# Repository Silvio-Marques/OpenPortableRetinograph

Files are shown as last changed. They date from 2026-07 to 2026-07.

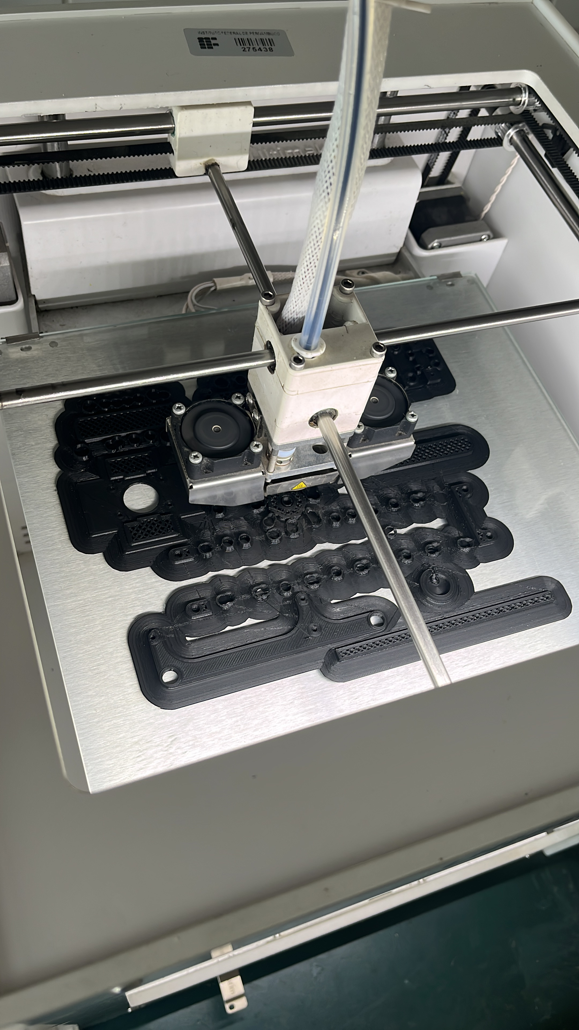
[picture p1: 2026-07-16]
images/Development/8934499A-B4BF-47F2-9E4D-7AB6EEFE7587.JPG

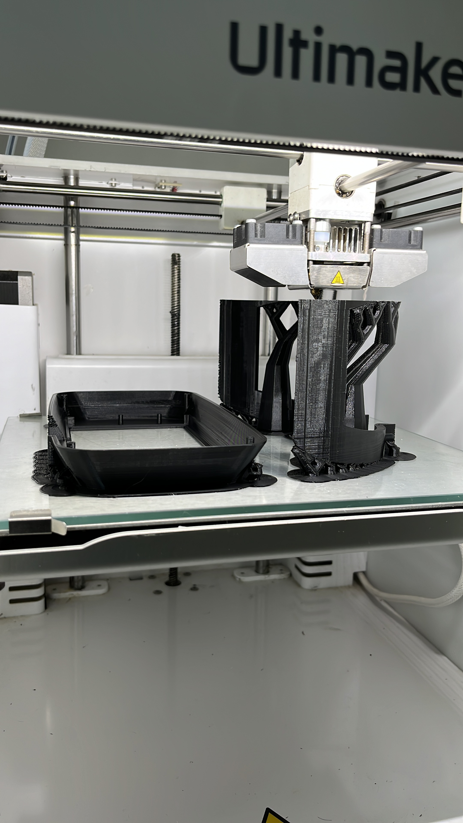
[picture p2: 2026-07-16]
images/Development/956187B9-EA5F-4862-9C40-ECFD5C4E084D.JPG

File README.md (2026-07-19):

# Open Portable Retinograph (OPR)

**Development of an Open-Source Portable Raspberry Pi-Based Retinograph for Retinal Image Acquisition and Automated Retinopathy Screening**

---

# Authors

**Developed by**

Silvio Marques (IFPE)

**Advisors**

Tiago Lima (IFPE)

Helio Bentzen (IFPE)

David Ribeiro (IFPE)

**Institution**

IFPE – Palmares Campus

Maker Laboratory – Palmares Campus

Brazil

---

# About the Project

The **Open Portable Retinograph (OPR)** is an open-hardware project developed to provide a portable, low-cost platform for retinal fundus image acquisition.

The project combines additive manufacturing, commercially available optical components, and a Raspberry Pi-based embedded platform to enable retinal image acquisition using open-source hardware, with a focus on research, education, and future automated retinopathy screening applications.

The system architecture was designed to reduce the cost of conventional retinal imaging devices, facilitate replication by other institutions, and provide a platform for the future integration of embedded Artificial Intelligence algorithms.

---

# License

This project is distributed under the **MIT License**.

The CAD files, technical documentation, source code, and computational models may be used, modified, and redistributed under the terms of the license.

---

# Disclaimer

This equipment is intended exclusively for research, technological development, and educational purposes.

The prototype **is not certified for clinical use** and must not be used for medical diagnosis without the appropriate approval from the relevant regulatory authorities.

---

# Software Ecosystem

The retinograph was designed with a modular architecture, allowing integration with different Artificial Intelligence systems for the analysis of acquired retinal images.

## OpenDR

Automated Diabetic Retinopathy screening system.

**Repository:**

https://github.com/heliobentzen/openDR

**Key Features**

* Automated image acquisition
* Web interface
* TensorFlow Lite
* Grad-CAM
* Report generation
* Automatic classification

---

## Glaucoma AI

Deep Learning–based system for glaucoma classification from retinal images.

**Demo:**

https://huggingface.co/spaces/tiagopessoalim/glaucoma

**Intended Applications**

* Diagnostic second opinion
* Glaucoma screening support

---

# Version

**Current Version**

**v1.0.0 (Functional Prototype)**

---

# Version 1.0 Highlights

* Complete mechanical architecture developed
* Fully parametric CAD design
* Optical system based on a 20D condensing lens
* Integration of first-surface mirrors
* Structure manufactured using 3D printing
* TPU facial support
* Raspberry Pi 4 fully integrated into the system
* M12 camera integration
* High-power LED illumination system
* Web-based remote operation interface
* Wi-Fi communication between the Raspberry Pi and a smartphone
* Retinal image acquisition
* Functional prototype validated under laboratory bench conditions

---

# Objectives

* Develop an open-source portable retinograph
* Reduce the cost of retinal imaging equipment
* Facilitate platform replication
* Enable future embedded Artificial Intelligence applications
* Support research in Ophthalmology and Biomedical Engineering

---

# Features

## Mechanical Structure

* Complete CAD design
* 3D-printed structure
* Modular architecture
* Focus adjustment through optical housing displacement
* TPU facial support

---

## Optical System

* 20-diopter condensing lens
* First-surface mirrors
* M12 lens
* Anti-reflective internal coating
* Adjustable optical alignment

---

## Hardware

* Raspberry Pi 4
* M12 camera module
* High-power LEDs
* Rechargeable battery
* Wi-Fi connectivity

---

## User Interface

* Remote image acquisition
* Real-time visualization
* Image storage
* Browser-based control
* Compatible with smartphones and computers

---

# Prototype Specifications

| Feature | Value |
| --- | ---: |
| Development time | 5 months |
| Weight | ~800 g |
| Cost | US$491 |
| Structure | PLA + TPU + MDF |
| Communication | Wi-Fi |
| Interface | Web |
| Battery life | ~40 minutes |
| Boot time | ~2 minutes |
| Simultaneous devices | 2 |

---

# Project Organization

```text
OpenPortableRetinograph/
│
├── hardware/
│   Files related to hardware development,
│   including CAD models, STL files, technical drawings,
│   bill of materials (BOM), schematics,
│   and prototype assembly documentation.
│
├── software/
│   Source code used by the retinograph,
│   including Raspberry Pi applications,
│   the web interface,
│   and image processing algorithms.
│
├── images/
│   Development photographs,
│   prototype images,
│   rendered CAD models,
│   and experimental results obtained
│   during equipment testing.
│
└── README.md
    Main project documentation.
```

As the project evolves, additional directories may be added for technical documentation, Artificial Intelligence models, scientific publications, and experimental results.

---

# Current Status

| Module | Status |
| --- | :----: |
| CAD Design | ✅ |
| Optical System | ✅ |
| 3D Printing | ✅ |
| Raspberry Pi Integration  | ✅ |
| Web Interface | ✅ |
| Retinal Image Acquisition | ✅ |
| Optical Testing | ✅ |
| Artificial Intelligence | |
| Clinical Validation | |

---

# Future Work

* Optical system optimization
* Development of a miniaturized version
* TensorFlow Lite model integration
* Automatic retinal segmentation
* Automated retinopathy classification
* Dedicated mobile application
* Clinical validation
* Open-hardware publication

---

# Acknowledgments

The authors would like to thank the institutions and collaborators involved in the development of this project, as well as the Open Hardware community and the Open Indirect Ophthalmoscope (OIO), Raspberry Pi Foundation, and OpenCV projects, which served as important sources of inspiration for the development of this platform.

---

# Contact

**Author**

[smxj@discente.ifpe.edu.br](mailto:smxj@discente.ifpe.edu.br)

**GitHub**

https://github.com/usuario/OpenPortableRetinograph

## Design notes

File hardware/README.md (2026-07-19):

# Hardware

This directory contains all the files required for the manufacturing, assembly, and maintenance of the portable retinograph.

---

# Directory Structure

**CAD/** – Editable CAD models

**STL/** – Files for 3D printing

**BOM/** – Bill of Materials

**Drawings/** – Technical drawings

---

# Physical Architecture

*(Diagram)*

---

# Manufacturing Process

CAD Design

↓

3D Printing

↓

Post-Processing

↓

Mechanical Assembly

↓

Optical Assembly

↓

Electronic Integration

↓

Optical Alignment

↓

Testing

---

# Mechanical Specifications

* Weight
* Dimensions
* Materials
* Manufacturing technology

---

# Optical Specifications

* 20D condensing lens
* First-surface mirrors
* M12 lens
* Field of view

---

# Electronic Specifications

* Raspberry Pi 4
* M12 camera module
* LEDs
* Battery
* Wi-Fi connectivity

---

# References

* Open Indirect Ophthalmoscope (OIO)
* Raspberry Pi
* Open Hardware

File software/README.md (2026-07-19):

# Software

The **Open Portable Retinograph (OPR)** software is responsible for hardware control, retinal image acquisition, user interaction, and the execution of image processing and Artificial Intelligence algorithms.

The software architecture was designed with a modular approach, allowing each component to be developed and maintained independently.

---

# Directory Structure

```text
software/
├── Web Interface/
│   └── openDR/
│
├── RaspberryPi/
│
├── glaucoma/
│
└── README.md
```

---

# Directories

## Web Interface/openDR/

Contains the graphical user interface used to operate the retinograph.

**Key Features**

* Real-time camera preview
* Image acquisition
* Browser-based remote control
* Wi-Fi communication with the Raspberry Pi
* Image storage
* Responsive interface for smartphones and desktop computers
* Integration with the image processing pipeline

**Technologies**

* Python
* Flask
* HTML
* CSS
* JavaScript
* OpenCV

---

## RaspberryPi/

Contains all software executed directly on the Raspberry Pi.

**Responsibilities**

* System initialization
* M12 camera control
* LED illumination control
* GPIO communication
* Storage management
* Wi-Fi network configuration
* Communication with the Web Interface

---

## glaucoma/

Contains the Artificial Intelligence algorithms used for retinal image analysis.

This directory includes:

* Trained models
* Image preprocessing
* Segmentation
* Classification
* Grad-CAM visualization generation
* Local inference

The models can be executed locally on the Raspberry Pi or remotely through the Hugging Face Spaces platform.

---

# Software Workflow

```text
Raspberry Pi
      │
      ▼
Web Interface
      │
      ▼
Image Acquisition
      │
      ▼
Preprocessing
      │
      ▼
Artificial Intelligence
      │
      ▼
Results
```

---

# Dependencies

* Python 3.11+
* Flask
* OpenCV
* NumPy
* Picamera2
* libcamera
* pigpio
* Requests
* PyTorch
* Torchvision
* TensorFlow Lite

---

# Execution

1. Power on the Raspberry Pi.
2. Start the Flask server.
3. Connect a smartphone or computer via Wi-Fi.
4. Access the Web Interface.
5. Capture a retinal image.
6. Execute image processing and AI inference.

---

# Development

Each module can be updated independently.

The modular directory structure simplifies:

* Maintenance
* Testing
* Continuous integration
* Component reuse
* Collaborative development

---

# Related Projects

* OpenDR
* Hugging Face Spaces (Glaucoma)
* Raspberry Pi OS
* OpenCV

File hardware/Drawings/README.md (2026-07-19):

# Drawings

This directory contains the assembly drawings used for the construction of the portable retinograph.

The documents provided serve as references for mechanical assembly, optical component positioning, and embedded hardware integration.

---

# Files

## Componentes.pdf

Exploded-view drawing of the retinograph showing all components used in the assembly.

The main components are identified as follows:

| Identifier | Description |
| --- | --- |
| A | Facial support (TPU) |
| B | Optical housing |
| C | Main enclosure |
| D | Smartphone mount |
| E | LCD display adapter (optional) |
| F | First-surface mirrors |
| G | Mirror holder |
| H | Condensing lens holder |
| I | Raspberry Pi 4 |
| J | M12 camera module |
| K | Smartphone (Web interface) |
| L | +20D condensing lens |
| M | Electronic circuit board |
| N | LED illumination system |

---

## Esquema.pdf

Dimensional drawing of the prototype.

It includes:

* External dimensions
* Subassembly layout
* Optical alignment
* Camera position
* Condensing lens position
* Overall device dimensions

Approximate prototype dimensions:

* **Length:** 26 cm
* **Height:** 17 cm
* **Width:** 11 cm

---

# Assembly Sequence

The recommended assembly procedure is as follows:

1. Print the PLA and TPU components.
2. Fabricate the MDF structural base.
3. Assemble the optical housing.
4. Install the first-surface mirrors.
5. Install the condensing lens holder.
6. Mount the +20D condensing lens.
7. Install the M12 camera module.
8. Insert the optical housing into the main enclosure.
9. Adjust the focusing mechanism.
10. Install the LED illumination system.
11. Secure the Raspberry Pi 4.
12. Connect the camera, LEDs, and Raspberry Pi.
13. Install the electronic circuit board.
14. Connect the power supply.
15. Perform optical alignment tests.
16. Fine-tune the focus.
17. Establish the Wi-Fi connection using a smartphone.
18. Perform final image acquisition tests.

---

# Notes

* The facial support is manufactured from TPU to provide improved comfort and accommodate different facial anatomies.
* The system was designed to use a smartphone as the primary user interface, reducing the overall cost of the device.
* The architecture also supports the installation of a 5-inch or 3.5-inch LCD display, although this configuration is optional.
* All structural components were designed for additive manufacturing using 3D printing, enabling straightforward reproduction and maintenance of the device.

---

# Related Documentation

See also:

* `/hardware/CAD`
* `/hardware/STL`
* `/hardware/BOM`
* `/hardware/Schematics`
* `/hardware/Datasheets`

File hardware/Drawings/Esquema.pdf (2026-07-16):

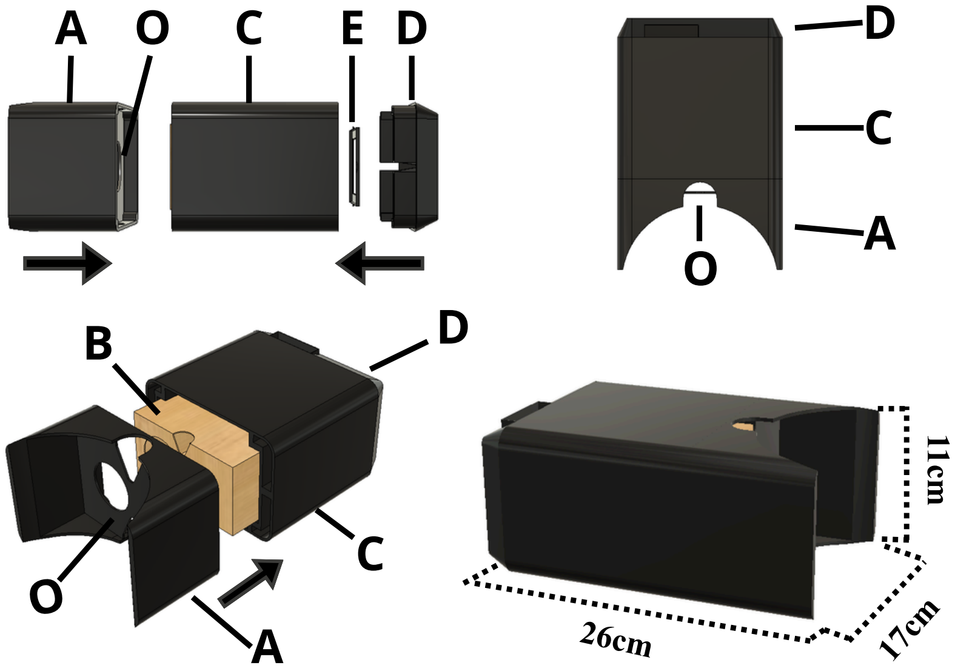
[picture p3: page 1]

A C E D

A

C

D

A

C

B D

26cm

17cm

11cm

O

O

O

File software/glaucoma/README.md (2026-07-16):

---
title: Glaucoma
emoji: 🏢
colorFrom: gray
colorTo: green
sdk: gradio
sdk_version: 6.14.0
python_version: '3.13'
app_file: app.py
pinned: false
---

Check out the configuration reference at https://huggingface.co/docs/hub/spaces-config-reference

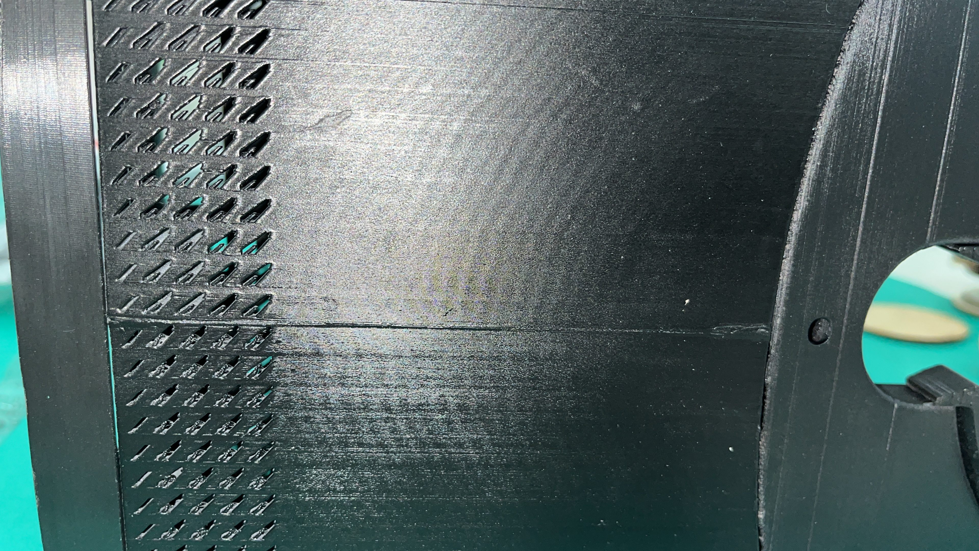
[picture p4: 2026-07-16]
images/Development/9094A2B2-7542-418E-A758-33E75812D285.JPG

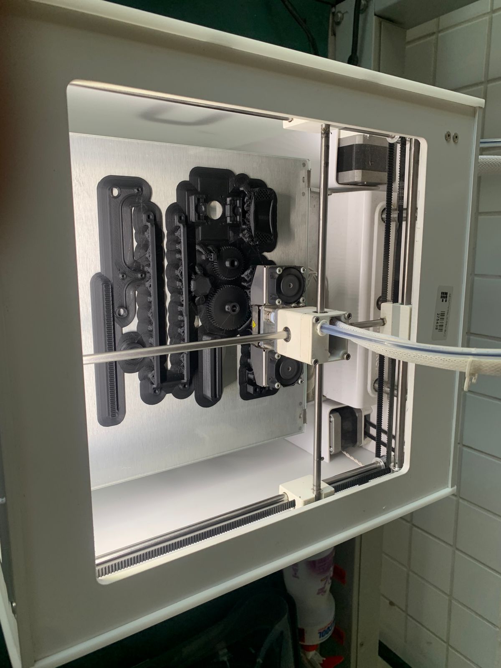
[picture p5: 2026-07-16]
images/Development/3d9d28ef-6450-4432-8e0f-05f08b67c73f.JPG

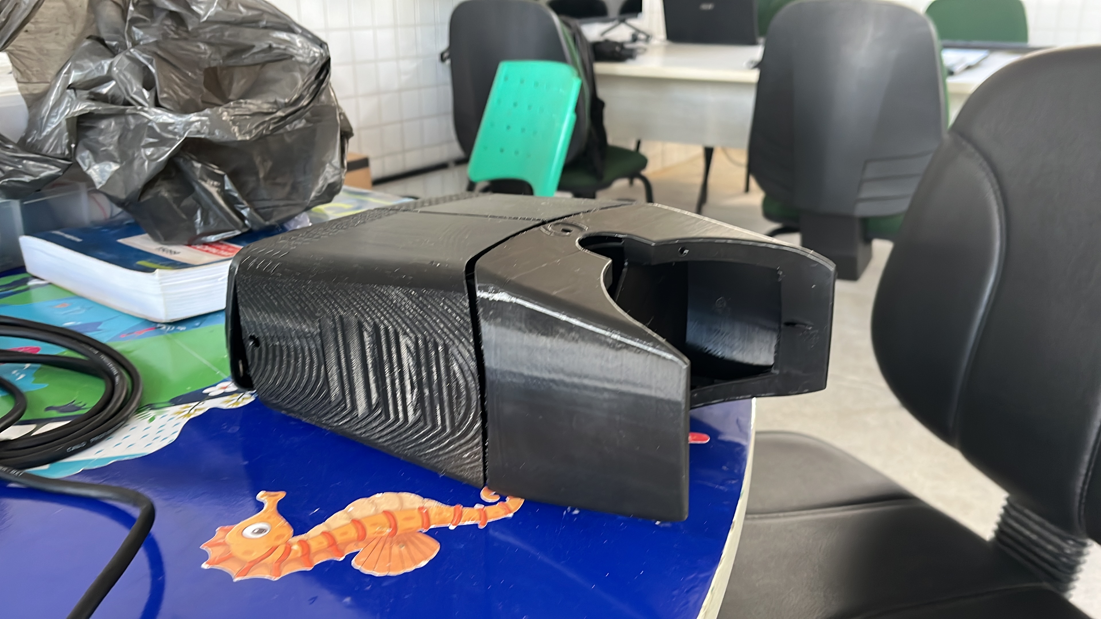
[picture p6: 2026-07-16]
images/Development/CB8158A3-E09E-4588-AF71-DEEE8C12A19D.JPG

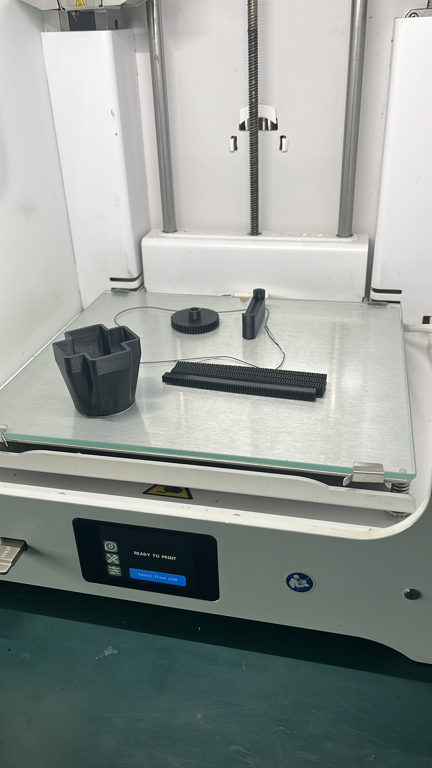
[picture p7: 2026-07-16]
images/Development/EB2D7882-216B-40A3-87E8-164483229CCA.JPG

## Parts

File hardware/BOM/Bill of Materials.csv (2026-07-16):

Item | Subsystem | Component | Specification | Manufacturer | Quantity | Unit | Unit Cost (USD) | Total Cost (USD) | Notes
M01 | Mechanical | Main Housing | 3D printed PLA enclosure | Custom | 1 | pcs |  |  | Printed in PLA
M02 | Mechanical | Optical Box | 3D printed PLA | Custom | 1 | pcs |  |  | Holds optical components
M03 | Mechanical | Smartphone Mount | 3D printed PLA | Custom | 1 | pcs |  |  | Wi-Fi interface support
M04 | Mechanical | Internal Supports | 3D printed PLA | Custom | 1 | set |  |  | Camera and Raspberry Pi supports
M05 | Mechanical | Rear Cover | 3D printed PLA | Custom | 1 | pcs |  |  | Electronic compartment cover
M06 | Mechanical | Face Support | 3D printed TPU | 2 | pcs |  |  | Available in different sizes
M07 | Mechanical | Base Plate | 3 mm MDF | Custom | 1 | pcs |  |  | Structural reinforcement
M08 | Mechanical | Fasteners | M3 screws | nuts and spacers | Commercial | 1 | set |  |  | Assembly hardware
O01 | Optical | Condensing Lens | +20D | Ø40 mm | BK7 | Volk | 1 | pcs | 210.00 | 210.00 | Main imaging lens
O02 | Optical | First Surface Mirror | 50 mm × 50 mm | Commercial | 2 | pcs |  |  | Optical path
O03 | Optical | M12 Lens | 3.6 mm F1.8 | Commercial | 1 | pcs |  |  | Camera lens
A01 | Acquisition | Raspberry Pi Camera Module | OV5647 5MP Sensor | Raspberry Pi Compatible | 1 | pcs | 16.00 | 16.00 | 1080p maximum resolution
C01 | Embedded Computing | Raspberry Pi 4 Model B | 2 GB RAM | Raspberry Pi Foundation | 1 | pcs |  |  | Main embedded computer
C02 | Embedded Computing | microSD Card | 16 GB Class 10 | Commercial | 1 | pcs |  |  | Operating system storage
C03 | Embedded Computing | GPIO Interface Board | Custom PCB | Custom | 1 | pcs |  |  | Peripheral connections
C04 | Embedded Computing | FFC Camera Cable | 15 cm | Commercial | 1 | pcs |  |  | Camera connection
L01 | Lighting | LED Ring | 3 W | 3 V | 120° | White | Commercial | 1 | pcs |  |  | Fundus illumination
L02 | Lighting | LED Driver | PWM Driver | Custom | 1 | pcs |  |  | Brightness control
L03 | Lighting | Wiring | Cables and connectors | Commercial | 1 | set |  |  | Electrical connections
P01 | Power | 18650 Battery | 3000 mAh Li-Ion | Commercial | 2 | pcs |  |  | Rechargeable batteries
P02 | Power | Voltage Regulator | 5 V / 5 A DC-DC Converter | Commercial | 1 | pcs |  |  | Power regulation
P03 | Power | Battery Holder | Dual 18650 Holder | Commercial | 1 | pcs |  |  | Battery support
S01 | Software | Web Interface | Flask-based GUI | Custom | 1 | license |  |  | Remote operation
S02 | Software | Operating System | Raspberry Pi OS | Open Source | 1 | license |  |  | Embedded Linux
S03 | Software | Camera Control | Python + OpenCV + Picamera2 | Open Source | 1 | license |  |  | Image acquisition
TOTAL |  | Estimated Hardware Cost |  |  |  |  | 491.00 | 491.00

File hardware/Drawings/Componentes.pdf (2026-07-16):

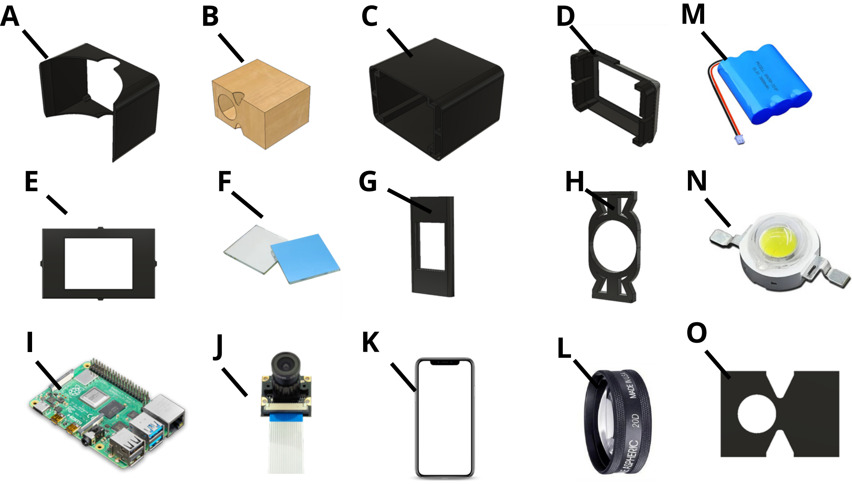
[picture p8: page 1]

D

F H

O

A | B | C

E

I | J | K | L

G N

M

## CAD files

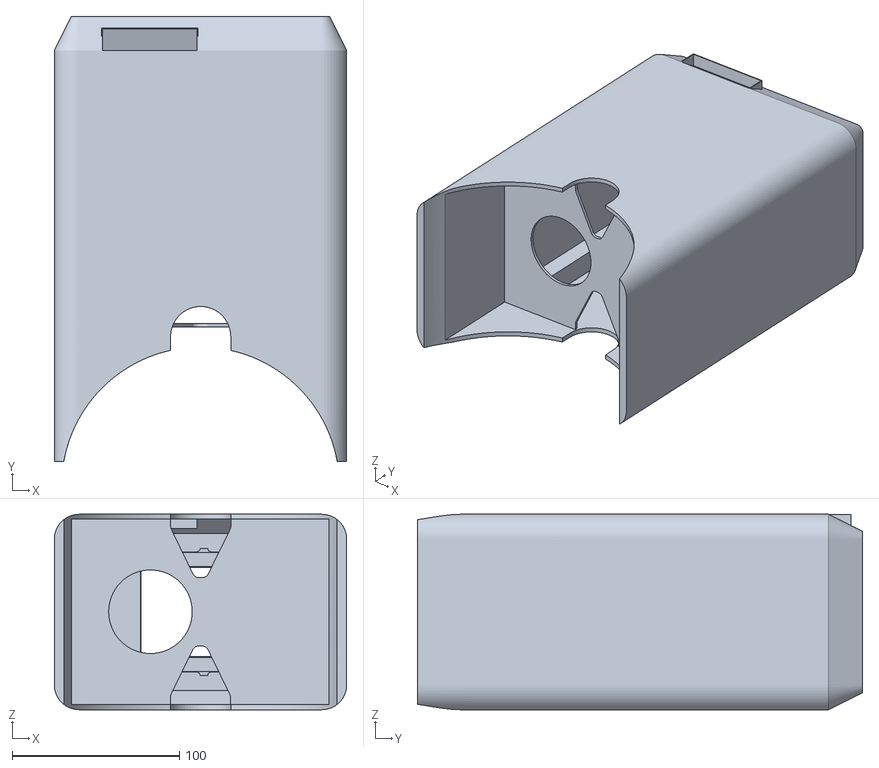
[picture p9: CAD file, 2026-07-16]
hardware/STL/MainCasings.stl
175.0 x 266.3 x 117.0

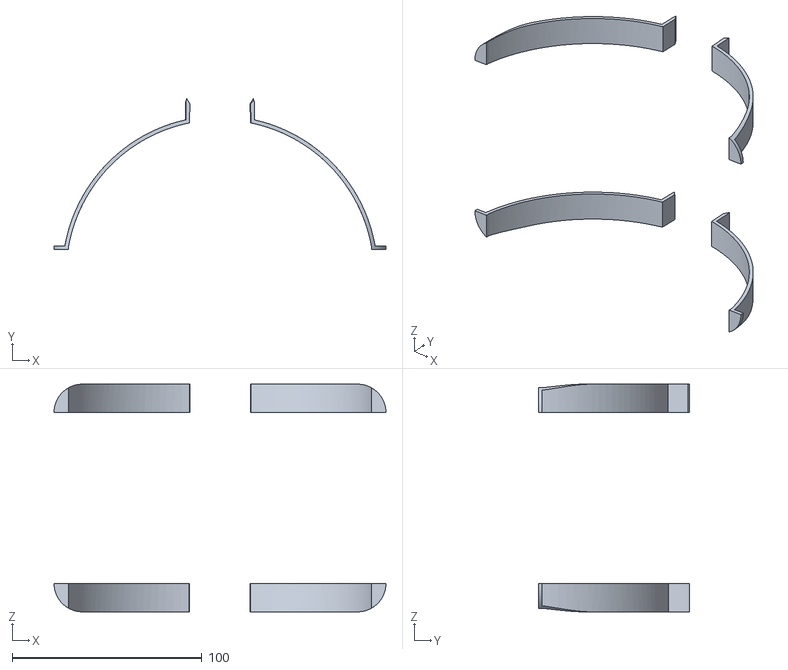
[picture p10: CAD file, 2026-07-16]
hardware/STL/FaceContact.stl
175.0 x 79.8 x 120.0

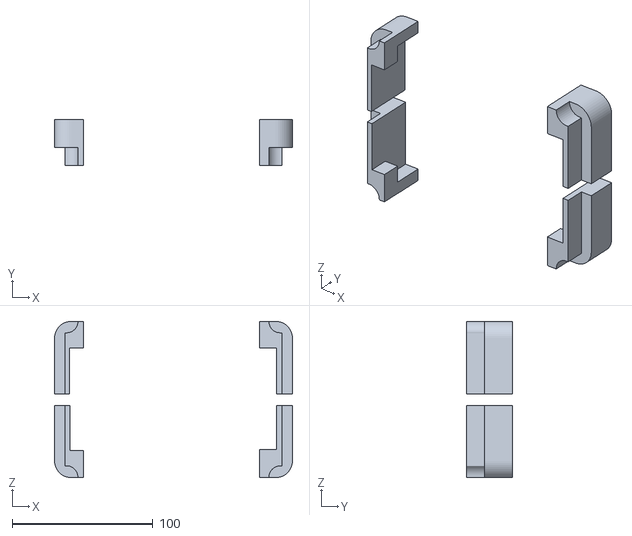
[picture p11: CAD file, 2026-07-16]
hardware/STL/Junctions.stl
169.0 x 33.0 x 111.0

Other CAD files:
hardware/CAD/FaceContact.f3d
hardware/CAD/Junctions.f3d
hardware/CAD/MainCasings.f3d

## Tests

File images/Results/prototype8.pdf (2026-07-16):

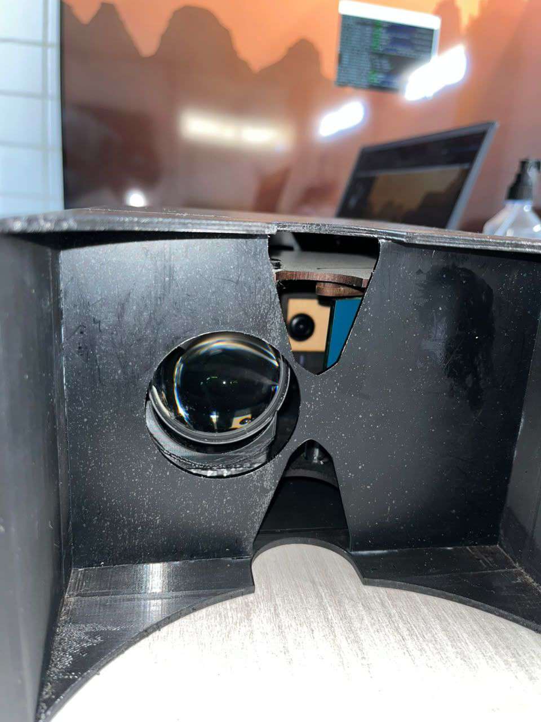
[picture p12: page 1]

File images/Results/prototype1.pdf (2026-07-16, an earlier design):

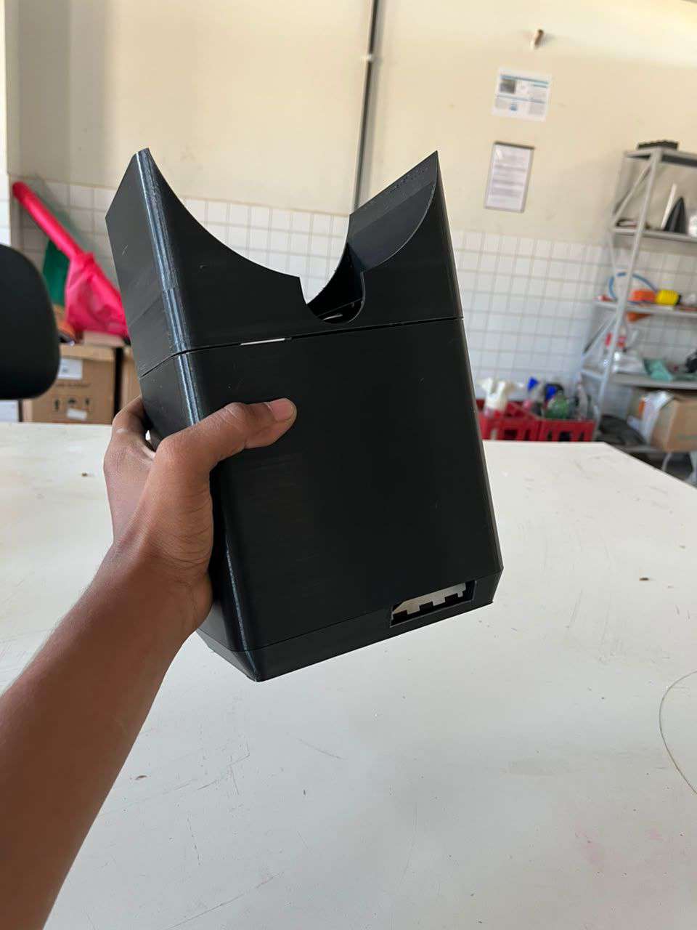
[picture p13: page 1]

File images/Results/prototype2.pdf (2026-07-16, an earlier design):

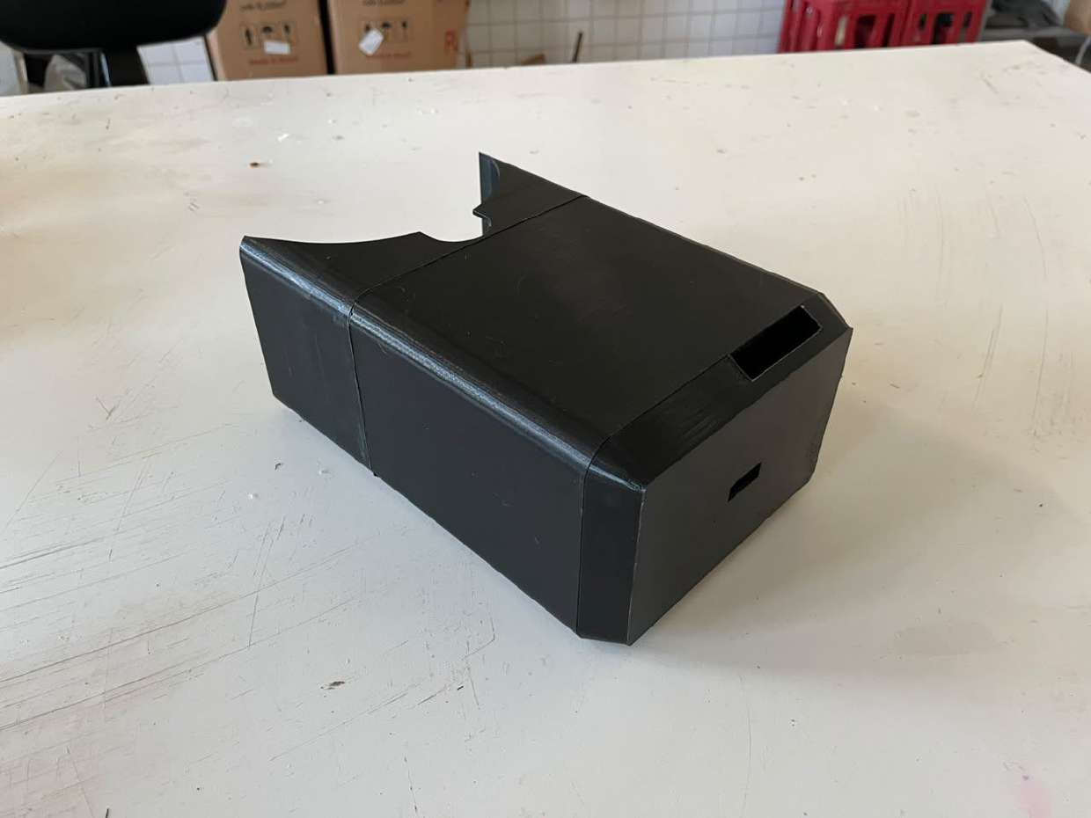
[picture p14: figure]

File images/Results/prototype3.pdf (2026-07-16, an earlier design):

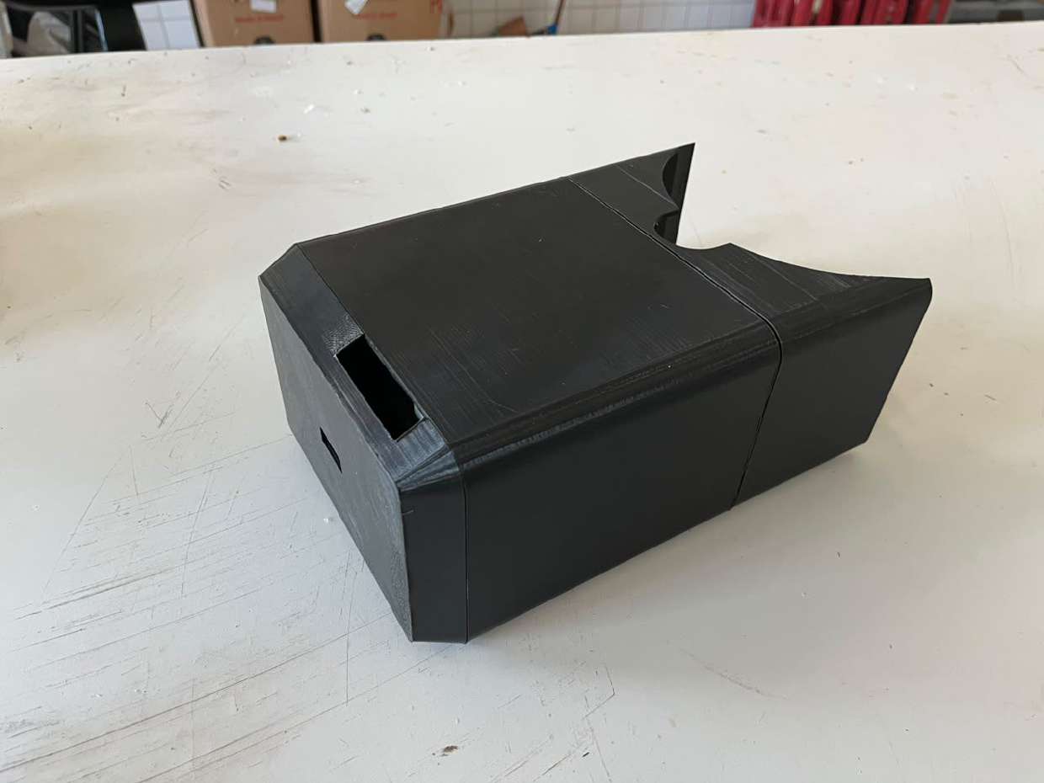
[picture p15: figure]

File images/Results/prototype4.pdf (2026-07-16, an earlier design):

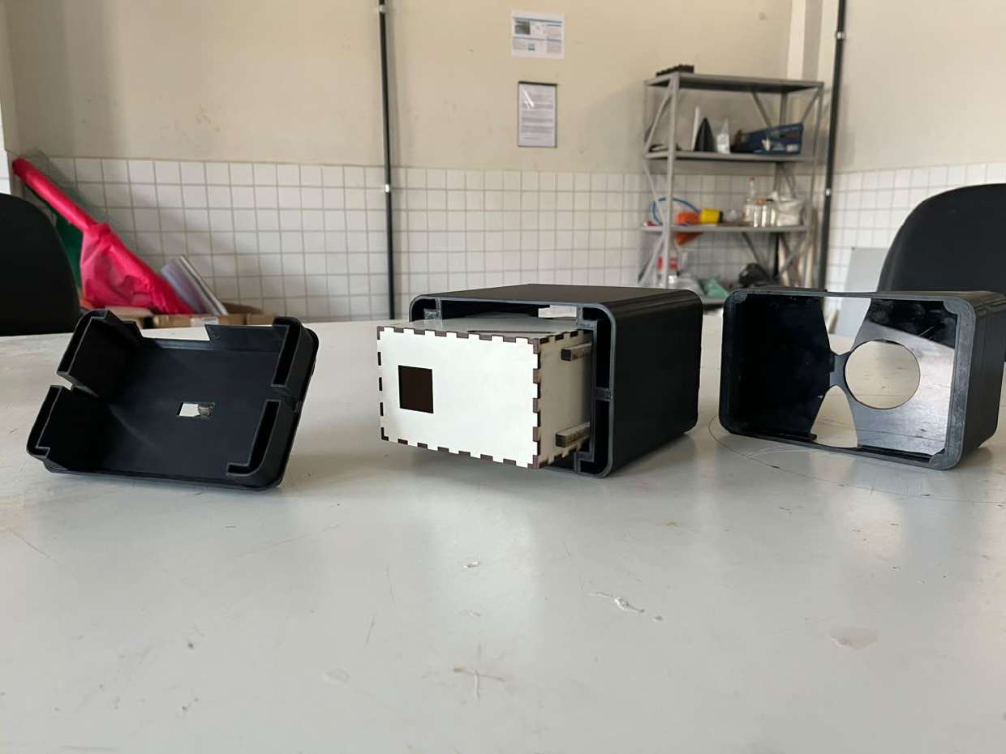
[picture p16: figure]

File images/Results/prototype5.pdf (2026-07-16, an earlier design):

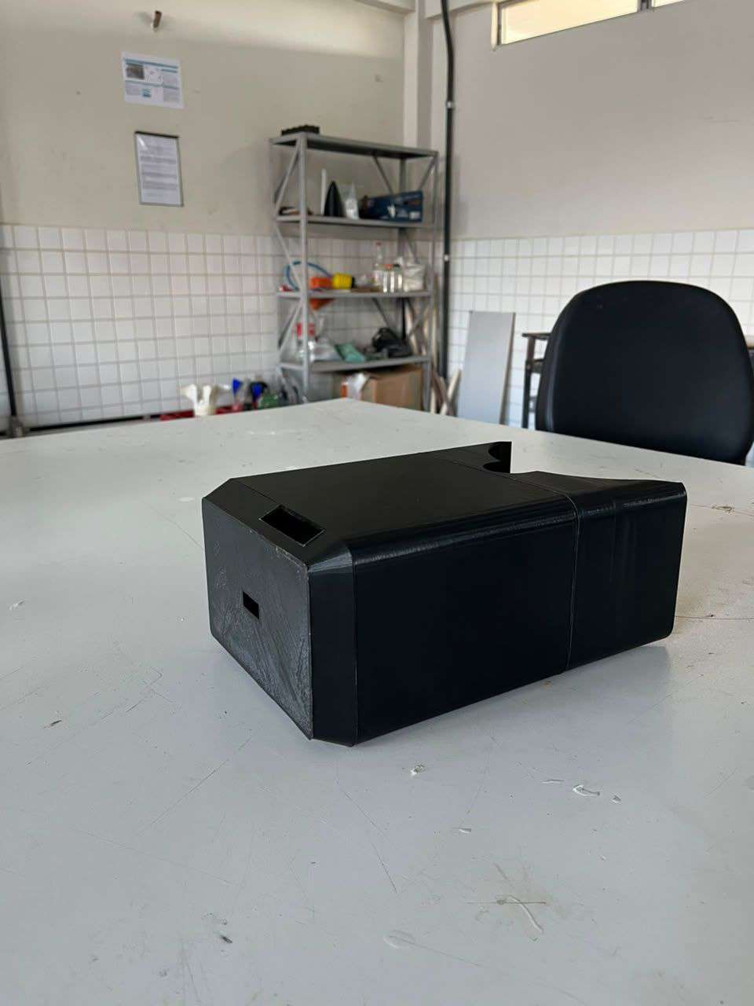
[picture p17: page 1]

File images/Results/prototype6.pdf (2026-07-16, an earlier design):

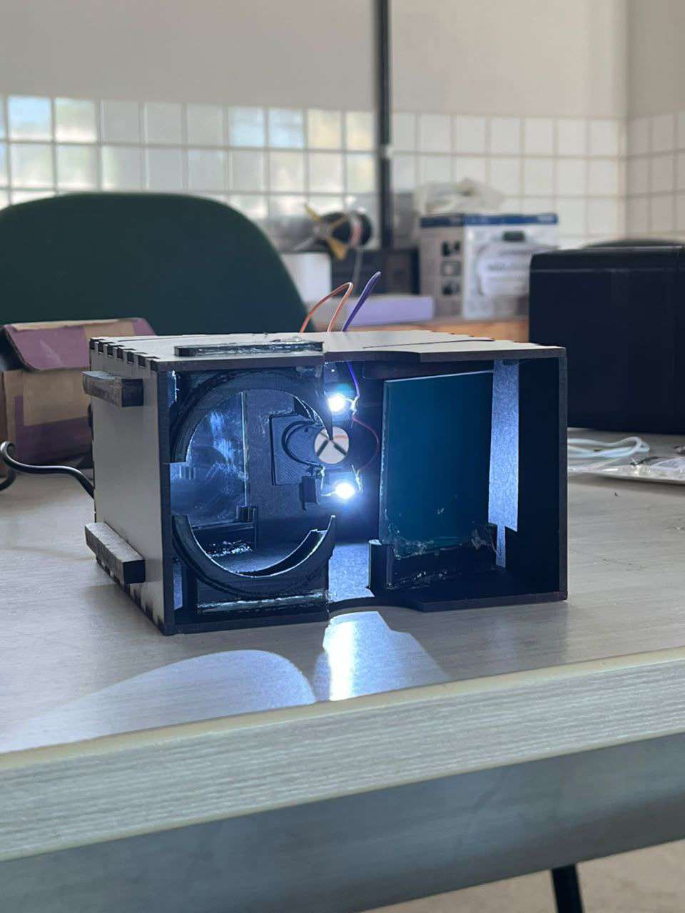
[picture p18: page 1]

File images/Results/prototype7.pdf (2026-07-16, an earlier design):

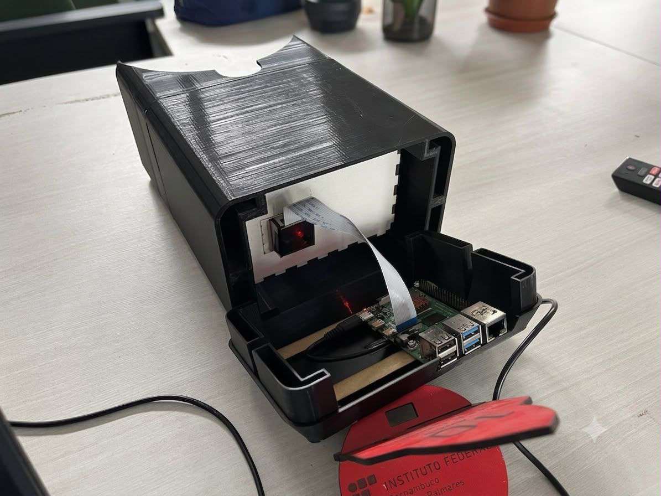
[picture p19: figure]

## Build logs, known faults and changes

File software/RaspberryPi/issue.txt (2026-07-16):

Raspberry Pi reference 2026-04-21
Generated using pi-gen, https://github.com/RPi-Distro/pi-gen, 4ad56cc850fa60adcc7f07dc15879bc95cc1d281, stage4

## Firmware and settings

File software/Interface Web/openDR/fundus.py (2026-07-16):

##############################################################################
##  OWL v3.0                                                          ########
## ------------------------------------------------------------       ########
##  Authors: Ayush Yadav, Devesh Jain, Ebin Philip, Dhruv Joshi       ########
##  Revision: Helio Bentzen                                           ########
##############################################################################

import atexit
import json
import os
import re
import subprocess
import time
from concurrent.futures import ThreadPoolExecutor
from copy import deepcopy
from datetime import datetime, timezone
from functools import lru_cache
from pathlib import Path
from threading import Lock
from uuid import uuid4

import cv2
import numpy as np
from flask import Flask, Response, abort, jsonify, redirect, render_template, request, send_from_directory, url_for
from werkzeug.utils import safe_join

from RetinaCamera import (
    CameraDisconnectedError,
    CameraOverheatError,
    RetinaCamera,
    RetinaCameraError,
)
from modules.process import (
    DEFAULT_PROCESSING_SETTINGS,
    grade,
    grade_with_explanation,
    normalize_processing_settings,
)

try:
    import pigpio
except ImportError:  # pragma: no cover - depends on Raspberry Pi runtime
    pigpio = None

app = Flask(__name__)
app.config["MAX_CONTENT_LENGTH"] = 25 * 1024 * 1024
BASE_FOLDER = Path(os.environ.get("OPEN_DR_BASE", "/home/pi/openDR")).resolve()
TOKENS = ["Flip", "Vid", "Click", "Switch", "Grade", "Explain", "Shut"]
PATIENT_ID_RE = re.compile(r"^[A-Z0-9_-]{1,64}$")
FOCUS_WARNING_MESSAGE = "Posicione o paciente e foque antes de capturar"
CAMERA_UNAVAILABLE_MESSAGE = (
    "Câmera indisponível - você ainda pode enviar fotos para análise"
)
MIN_FOCUS_SCORE = 140
DARK_PIXEL_THRESHOLD = 58
MIN_DARK_PIXELS = 120
MIN_DARK_DENSITY = 0.20
MIN_DARK_RATIO = 0.01
MAX_DARK_RATIO = 0.42
PREVIEW_MIN_INTERVAL_S = 0.20
INFERENCE_WORKER_COUNT = max(1, int(os.environ.get("OPEN_DR_INFERENCE_WORKERS", "2")))
MAX_INFERENCE_JOB_HISTORY = max(
    1, int(os.environ.get("OPEN_DR_MAX_INFERENCE_JOB_HISTORY", "8"))
)
INFERENCE_STEPS = (
    ("received", "Imagem recebida"),
    ("preprocessing", "Pré-processamento (limpeza de ruído)"),
    ("inference", "Inferência do modelo"),
    ("report", "Geração do relatório"),
)
CAPTURE_FILENAME_RE = re.compile(
    r"^(?P<patient_id>.+)_(?P<date>\d{8})_(?P<time>\d{12})_(?P<uuid>[0-9a-f]{32})_(?P<capture>\d+)\.jpg$"
)
GALLERY_DEFAULT_PAGE_SIZE = 12
GALLERY_MAX_PAGE_SIZE = 60
THUMBNAIL_DEFAULT_SIZE = 256
THUMBNAIL_MIN_SIZE = 96
THUMBNAIL_MAX_SIZE = 384
UPLOAD_ALLOWED_EXTENSIONS = {".jpg", ".jpeg", ".png"}
MAX_UPLOAD_BYTES = 25 * 1024 * 1024

orangeyellow = 14
bluegreen = 15
switch = 4
pi = None


def default_processing_settings():
    return dict(DEFAULT_PROCESSING_SETTINGS)


class CameraSessionState:
    def __init__(self):
        self.lock = Lock()
        self.camera = None
        self.camera_error = None
        self.last_img = None
        self.inference_job_id = None
        self.patient_id = ""
        self.processing_settings = default_processing_settings()

    def reset(self):
        self.inference_job_id = None
        self.patient_id = ""
        self.last_img = None
        self.camera_error = None
        self.processing_settings = default_processing_settings()

    def stop_camera(self):
        if self.camera is not None:
            self.camera.stop()
            self.camera = None

    def deactivate_camera(self, error_message):
        """Stop and clear the active camera after a hardware fault.

        Caller must hold ``self.lock``. Keeps the patient session (and thus
        photo upload) alive even though camera-based capture is now
        unavailable.
        """
        self.stop_camera()
        self.camera_error = error_message


state = CameraSessionState()
preview_rate_lock = Lock()
preview_last_request = {}
inference_jobs_lock = Lock()
inference_jobs = {}
inference_executor = ThreadPoolExecutor(
    max_workers=INFERENCE_WORKER_COUNT,
    thread_name_prefix="inference",
)


def get_processing_settings():
    with state.lock:
        return dict(state.processing_settings)


def update_processing_settings_from_request(form_data):
    current_settings = get_processing_settings()
    updated_settings = normalize_processing_settings(
        {
            "brightness": form_data.get("brightness", current_settings["brightness"]),
            "contrast": form_data.get("contrast", current_settings["contrast"]),
            "fundus_threshold": form_data.get(
                "fundus_threshold", current_settings["fundus_threshold"]
            ),
            "glare_threshold": form_data.get(
                "glare_threshold", current_settings["glare_threshold"]
            ),
        }
    )
    with state.lock:
        state.processing_settings = updated_settings
    return updated_settings


@atexit.register
def shutdown_inference_executor():
    inference_executor.shutdown(wait=False, cancel_futures=True)


def describe_camera_error(exc):
    """Translate a RetinaCameraError into a user-facing Portuguese message."""
    if isinstance(exc, CameraOverheatError):
        return "CÂMERA SUPERAQUECIDA - AGUARDE E TENTE NOVAMENTE"
    if isinstance(exc, CameraDisconnectedError):
        return "CÂMERA DESCONECTADA - VERIFIQUE O CABO"
    return CAMERA_UNAVAILABLE_MESSAGE


def start_camera_safely():
    """Start the retinal camera, tolerating missing or faulty hardware.

    Returns a ``(camera, error_message)`` pair where exactly one of the two
    is truthy. This lets a patient session proceed for photo-upload-only use
    when no camera is attached (e.g. a workstation without the capture rig).
    """
    try:
        return RetinaCamera().start(), None
    except RetinaCameraError as exc:
        app.logger.warning(
            "Camera unavailable, continuing session without it: %s", exc
        )
        return None, describe_camera_error(exc)


@app.route("/")
def my_form():
    normalON()
    return render_template("index.html")


@app.route("/", methods=["POST"])
def my_form_post():
    patient_id = sanitize_patient_id(request.form["text"].upper())
    if not patient_id:
        return render_template("index.html")

    make_a_dir(patient_id)
    camera, camera_error = start_camera_safely()
    with state.lock:
        state.stop_camera()
        state.patient_id = patient_id
        state.inference_job_id = None
        state.last_img = None
        state.camera = camera
        state.camera_error = camera_error
    return redirect(url_for("captureSimpleFunc"))


@app.route("/captureSimple", methods=["GET", "POST"])
def captureSimpleFunc():
    if request.method == "GET":
        return render_capture()

    processing_settings = update_processing_settings_from_request(request.form)

    if "d" not in request.form:
        return render_capture()

    d = request.form["d"]

    if d == "Click":
        if request.form.get("focus_ok") != "1":
            return render_capture(FOCUS_WARNING_MESSAGE)
        with state.lock:
            if state.camera is None or not state.patient_id:
                return render_capture("NO ACTIVE CAPTURE SESSION")
            try:
                image = state.camera.capture()
            except RetinaCameraError as exc:
                error_message = describe_camera_error(exc)
                state.deactivate_camera(error_message)
                return render_capture(error_message)
            if not is_eye_in_focus(image):
                return render_capture(FOCUS_WARNING_MESSAGE)
            state.last_img = save_captured_images(state.patient_id, image)
            state.inference_job_id = None
        return render_capture()

    if d == "Flip":
        with state.lock:
            if state.camera is None:
                return render_capture("NO ACTIVE CAPTURE SESSION")
            state.camera.flip_cam()
        return render_capture()

    if d == "Vid":
        with state.lock:
            if state.camera is None or not state.patient_id:
                return render_capture("NO ACTIVE CAPTURE SESSION")
            state.camera.continuous_capture()
            if not state.camera.wait_for_capture(timeout=5):
                return render_capture("CAPTURE TIMEOUT - RETRY OR CHECK CAMERA")
            if not state.camera.images:
                # RetinaCamera swallows hardware errors inside its background
                # thread and just stops early, so an empty result here means
                # the camera failed mid-recording rather than timed out.
                error_message = "FALHA NA CÂMERA DURANTE A GRAVAÇÃO"
                state.deactivate_camera(error_message)
                return render_capture(error_message)
            state.last_img = save_captured_images(state.patient_id, state.camera.images)
            state.inference_job_id = None
        return render_capture()

    if d == "Grade":
        with state.lock:
            last_img = state.last_img
        if last_img is None:
            return render_capture("NO IMAGE SPECIFIED")

        grade_result = str(grade(last_img, processing_settings=processing_settings))[:4]
        print("the grade is " + grade_result)
        return render_capture(grade_result)

    if d == "Explain":
        with state.lock:
            last_img = state.last_img
            active_job_id = state.inference_job_id
        if last_img is None:
            return render_capture("NO IMAGE SPECIFIED")

        if active_job_id and is_inference_job_running(active_job_id):
            return render_capture("INFERENCE IN PROGRESS", inference_job_id=active_job_id)

        job_id = create_inference_job(last_img)
        with state.lock:
            state.inference_job_id = job_id

        inference_executor.submit(
            run_explanation_job,
            job_id,
            last_img,
            dict(processing_settings),
        )
        return render_capture("PROCESSANDO...", inference_job_id=job_id)

    if d == "Switch":
        with state.lock:
            had_session = bool(state.patient_id)
            state.stop_camera()
            state.reset()
        if had_session:
            return redirect(url_for("my_form"))
        return render_capture()

    if d == "Shut":
        shut_down()
        return render_capture()

    return render_capture()


@app.route("/inference-status/<job_id>", methods=["GET"])
def inference_status(job_id):
    job = get_inference_job(job_id)
    if job is None:
        return jsonify({"error": "INFERENCE JOB NOT FOUND"}), 404

    return jsonify(serialize_inference_job(job))


@app.route("/preview-frame", methods=["GET"])
def preview_frame():
    client_key = request.remote_addr or "unknown"
    now = time.monotonic()
    with preview_rate_lock:
        last_request = preview_last_request.get(client_key, 0.0)
        if now - last_request < PREVIEW_MIN_INTERVAL_S:
            abort(429)
        preview_last_request[client_key] = now

    with state.lock:
        if state.camera is None:
            abort(404)
        try:
            preview = state.camera.capture_preview()
        except RetinaCameraError as exc:
            state.deactivate_camera(describe_camera_error(exc))
            abort(503)
    response = Response(preview.tobytes(), mimetype="image/jpeg")
    response.headers["Cache-Control"] = "no-store, no-cache, must-revalidate, max-age=0"
    response.headers["Pragma"] = "no-cache"
    return response


@app.route("/upload-image", methods=["POST"])
def upload_image():
    """Accept a user-uploaded fundus photo and make it the active image.

    The uploaded file is validated (extension, size, decodability), decoded
    with OpenCV to normalise any supported format to a JPEG on disk, and saved
    into the current patient's capture set via :func:`save_captured_images`.
    It then becomes ``state.last_img`` so it can be graded with the existing
    "Grade" / "Explain" controls, exactly like a camera capture.
    """
    with state.lock:
        patient_id = state.patient_id
    if not patient_id:
        return render_capture("NENHUMA SESSÃO ATIVA - INICIE UMA SESSÃO")

    uploaded = request.files.get("image")
    if uploaded is None or not uploaded.filename:
        return render_capture("NENHUM ARQUIVO ENVIADO")

    if Path(uploaded.filename).suffix.lower() not in UPLOAD_ALLOWED_EXTENSIONS:
        return render_capture("FORMATO INVÁLIDO - ENVIE JPG OU PNG")

    file_bytes = uploaded.read()
    if not file_bytes:
        return render_capture("ARQUIVO VAZIO")
    if len(file_bytes) > MAX_UPLOAD_BYTES:
        return render_capture("ARQUIVO MUITO GRANDE (MÁX. 25 MB)")

    image = cv2.imdecode(np.frombuffer(file_bytes, dtype=np.uint8), cv2.IMREAD_COLOR)
    if image is None:
        return render_capture("IMAGEM INVÁLIDA OU CORROMPIDA")

    with state.lock:
        if not state.patient_id:
            return render_capture("NENHUMA SESSÃO ATIVA - INICIE UMA SESSÃO")
        state.last_img = save_captured_images(state.patient_id, image)
        state.inference_job_id = None
    return render_capture("IMAGEM ENVIADA")


def is_eye_in_focus(image_buffer):
    gray_frame = cv2.imdecode(image_buffer, cv2.IMREAD_GRAYSCALE)
    if gray_frame is None:
        return False

    resized = cv2.resize(gray_frame, (176, 132), interpolation=cv2.INTER_AREA)
    focus_score = cv2.Laplacian(resized, cv2.CV_64F).var()

    _, dark_regions = cv2.threshold(
        resized,
        DARK_PIXEL_THRESHOLD,
        255,
        cv2.THRESH_BINARY_INV,
    )
    dark_pixel_count = int(cv2.countNonZero(dark_regions))
    if dark_pixel_count < MIN_DARK_PIXELS:
        return False

    contours, _ = cv2.findContours(dark_regions, cv2.RETR_EXTERNAL, cv2.CHAIN_APPROX_SIMPLE)
    if not contours:
        return False

    largest_contour = max(contours, key=cv2.contourArea)
    contour_area = cv2.contourArea(largest_contour)
    x, y, width, height = cv2.boundingRect(largest_contour)
    bounding_area = max(1, width * height)
    dark_density = contour_area / bounding_area
    dark_ratio = dark_pixel_count / float(resized.shape[0] * resized.shape[1])
    has_eye_contour = (
        dark_density > MIN_DARK_DENSITY
        and dark_ratio > MIN_DARK_RATIO
        and dark_ratio < MAX_DARK_RATIO
    )
    return focus_score >= MIN_FOCUS_SCORE and has_eye_contour


def render_capture(
    grade_message="",
    overlay_filename=None,
    json_filename=None,
    dr_label=None,
    confidence=None,
    lesion_count=None,
    inference_job_id=None,
):
    with state.lock:
        patient_id = state.patient_id
        camera_available = state.camera is not None
        camera_warning = state.camera_error
    return render_template(
        "capture_simple.html",
        params=TOKENS,
        grades={"grade": grade_message},
        focus_warning_message=FOCUS_WARNING_MESSAGE,
        overlay_filename=overlay_filename,
        json_filename=json_filename,
        dr_label=dr_label,
        confidence=confidence,
        lesion_count=lesion_count,
        inference_job_id=inference_job_id,
        patient_id=patient_id,
        camera_available=camera_available,
        camera_warning=camera_warning,
        gallery_page_size=GALLERY_DEFAULT_PAGE_SIZE,
        processing_settings=get_processing_settings(),
        processing_defaults=default_processing_settings(),
        max_upload_bytes=MAX_UPLOAD_BYTES,
        upload_allowed_extensions=sorted(UPLOAD_ALLOWED_EXTENSIONS),
    )


def format_grade_display(grade_value):
    if grade_value is None:
        return ""
    return str(grade_value)[:4]


def create_inference_job(image_path):
    raw_filename = Path(image_path).name
    job_id = str(uuid4())
    steps = {
        key: {
            "key": key,
            "label": label,
            "status": "pending",
            "detail": "",
            "image_filename": raw_filename if key == "received" else None,
        }
        for key, label in INFERENCE_STEPS
    }
    steps["received"]["status"] = "completed"
    steps["preprocessing"]["status"] = "running"

    with inference_jobs_lock:
        inference_jobs[job_id] = {
            "job_id": job_id,
            "created_at": time.time(),
            "status": "running",
            "current_step": "preprocessing",
            "message": "Imagem enviada para a fila de inferência.",
            "error": "",
            "grade_message": "",
            "steps": steps,
            "result": {},
        }
        prune_inference_jobs_locked()

    return job_id


def prune_inference_jobs_locked():
    """Prune the oldest completed or failed jobs while holding the job lock."""
    terminal_job_ids = [
        job_id
        for job_id, job in sorted(
            inference_jobs.items(), key=lambda item: item[1].get("created_at", 0.0)
        )
        if job["status"] != "running"
    ]
    prune_count = len(terminal_job_ids) - MAX_INFERENCE_JOB_HISTORY
    if prune_count <= 0:
        return
    for job_id in terminal_job_ids[:prune_count]:
        inference_jobs.pop(job_id, None)


def is_inference_job_running(job_id):
    with inference_jobs_lock:
        job = inference_jobs.get(job_id)
        return job is not None and job["status"] == "running"


def get_inference_job(job_id):
    with inference_jobs_lock:
        job = inference_jobs.get(job_id)
        return deepcopy(job) if job is not None else None


def advance_inference_job(job_id, completed_step, next_step=None, **payload):
    with inference_jobs_lock:
        job = inference_jobs.get(job_id)
        if job is None:
            return

        completed_state = job["steps"][completed_step]
        completed_state["status"] = "completed"

        processed_path = payload.get("processed_path")
        if completed_step == "preprocessing" and processed_path:
            completed_state["image_filename"] = Path(processed_path).name
            completed_state["detail"] = "Ruído removido e imagem preparada."
            job["message"] = "Pré-processamento concluído."
        elif completed_step == "inference":
            job["grade_message"] = format_grade_display(payload.get("theia_grade"))
            completed_state["detail"] = (
                f"Resultado do modelo: {job['grade_message'] or 'N/A'}"
            )
            job["message"] = "Inferência do modelo concluída."
        elif completed_step == "report":
            gradcam_record = payload["gradcam"]
            overlay_filename = Path(gradcam_record["gradcam_overlay"]).name
            json_filename = Path(gradcam_record["gradcam_audit_json"]).name
            job["grade_message"] = format_grade_display(payload.get("theia_grade"))
            completed_state["image_filename"] = overlay_filename
            completed_state["detail"] = "Relatório final disponível."
            job["result"] = {
                "overlay_filename": overlay_filename,
                "json_filename": json_filename,
                "dr_label": gradcam_record["predicted_dr_grade"]["label"],
                "confidence": gradcam_record["predicted_dr_grade"]["confidence"],
                "lesion_count": len(gradcam_record["lesion_regions"]),
            }
            job["message"] = "Relatório final gerado."

        if next_step is not None:
            job["current_step"] = next_step
            job["steps"][next_step]["status"] = "running"
        else:
            job["current_step"] = None
            job["status"] = "completed"


def fail_inference_job(job_id, error_message):
    with inference_jobs_lock:
        job = inference_jobs.get(job_id)
        if job is None:
            return

        current_step = job.get("current_step")
        if current_step:
            job["steps"][current_step]["status"] = "failed"
        job["status"] = "failed"
        job["error"] = error_message
        job["message"] = error_message
        job["current_step"] = None


def serialize_inference_job(job):
    result = job["result"]
    serialized_steps = []
    for step_key, step_label in INFERENCE_STEPS:
        step = job["steps"][step_key]
        image_filename = step.get("image_filename")
        serialized_steps.append(
            {
                "key": step_key,
                "label": step_label,
                "status": step["status"],
                "detail": step.get("detail", ""),
                "image_url": (
                    url_for("serve_image", filename=image_filename)
                    if image_filename
                    else None
                ),
            }
        )

    overlay_filename = result.get("overlay_filename")
    json_filename = result.get("json_filename")
    return {
        "job_id": job["job_id"],
        "status": job["status"],
        "current_step": job["current_step"],
        "message": job["message"],
        "error": job["error"],
        "grade_message": job["grade_message"],
        "steps": serialized_steps,
        "result": {
            "overlay_image_url": (
                url_for("serve_image", filename=overlay_filename)
                if overlay_filename
                else None
            ),
            "json_url": (
                url_for("serve_image", filename=json_filename)
                if json_filename
                else None
            ),
            "dr_label": result.get("dr_label"),
            "confidence": result.get("confidence"),
            "lesion_count": result.get("lesion_count"),
        },
    }
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
